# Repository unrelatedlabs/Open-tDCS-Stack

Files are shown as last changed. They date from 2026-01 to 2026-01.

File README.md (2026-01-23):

<!--
SPDX-License-Identifier: CC-BY-SA-4.0
Copyright (C) 2024-2026 Peter Kuhar and OpenTDCS Contributors
-->

# Open-tDCS-Stack

Open-source transcranial Direct Current Stimulation (tDCS) device using the Seeed Studio XIAO BLE nRF52840.

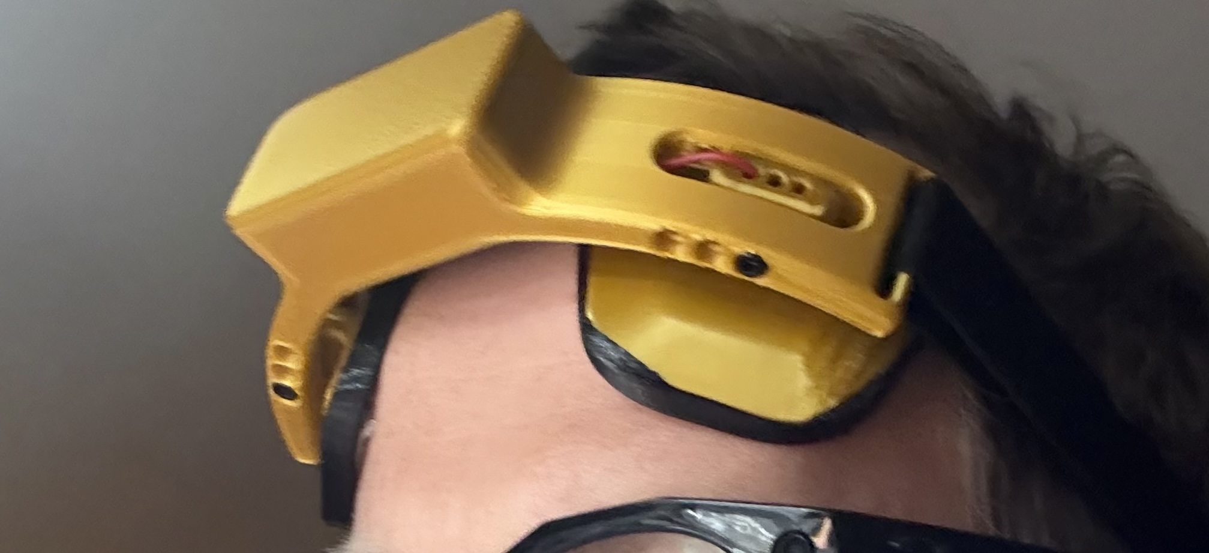
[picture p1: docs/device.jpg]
device photo
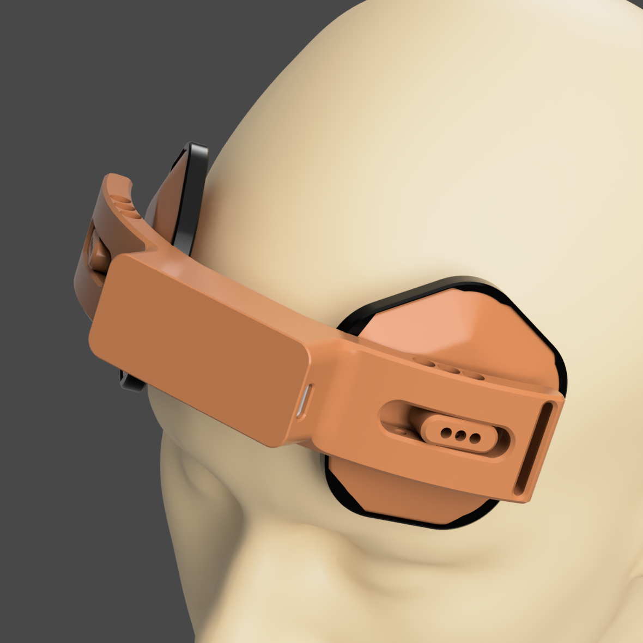
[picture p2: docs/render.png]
render
 

> Disclaimer: This is not a medical device. See `DISCLAIMER.md`.

## ⚠️ Safety Warning (tDCS / tES)

This open-source project is **not a certified medical device**. **Incorrect assembly, wiring, or electrode setup can cause dangerous current delivery**, leading to **skin burns/lesions**, unintended stimulation effects, equipment failure, or electric shock. tDCS/tES should only be performed with **medical-grade, certified equipment** and appropriate screening/supervision—**do not use DIY devices or unvalidated protocols on a person**.

### Sources
- IFCN (2015) "Transcranial electric stimulation in do-it-yourself applications" (PDF):  
  https://www.neurofyziologie.cz/doc/IFCNinfo/Using_tES_devices_as_DIY_FINAL_13Dec15.pdf
- Wurzman et al. (2016) "An open letter concerning do-it-yourself users of tDCS" (free full text, PMC):  
  https://pmc.ncbi.nlm.nih.gov/articles/PMC6050584/
- Fitz & Reiner (2015) "The challenge of crafting policy for do-it-yourself brain stimulation" (PubMed):  
  https://pubmed.ncbi.nlm.nih.gov/23733050/
- Bikson et al. (2016) "Safety of tDCS: Evidence-based update" (PubMed):  
  https://pubmed.ncbi.nlm.nih.gov/27372845/
- IFCN (Oct 2025) "Low intensity transcranial electric stimulation: Safety… guidelines 2017–2025 update" (PDF):  
  https://www.ifcn.info/UserFiles/file/CLINPH-S-25-01153_Targeted-Safety-Guidelines-update-Oct-2025.pdf
- Loo et al. (2011) "Avoiding skin burns with tDCS" (PubMed):  
  https://pubmed.ncbi.nlm.nih.gov/20923600/
- Rodríguez et al. (2014) "Skin lesions induced by tDCS" (PubMed):  
  https://pubmed.ncbi.nlm.nih.gov/25073936/
- "Skin Lesions Induced by tDCS" (PDF letter):  
  https://www.tmslab.org/publications/532.pdf
- Chao et al. (2018) "Hypomania induced by bifrontal tDCS" (free full text, PMC):  
  https://pmc.ncbi.nlm.nih.gov/articles/PMC6166027/

## Overview

Open-tDCS-Stack is a Bluetooth-enabled tDCS device that provides precise current control with real-time monitoring capabilities through a web interface.

## Hardware

- **Microcontroller**: Seeed Studio XIAO BLE nRF52840
- **Connectivity**: Bluetooth 5.0 (BLE)
- **Current Range**: 0-2.5mA (configurable)
- **Battery**: 3.7V LiPo

### Schematics 

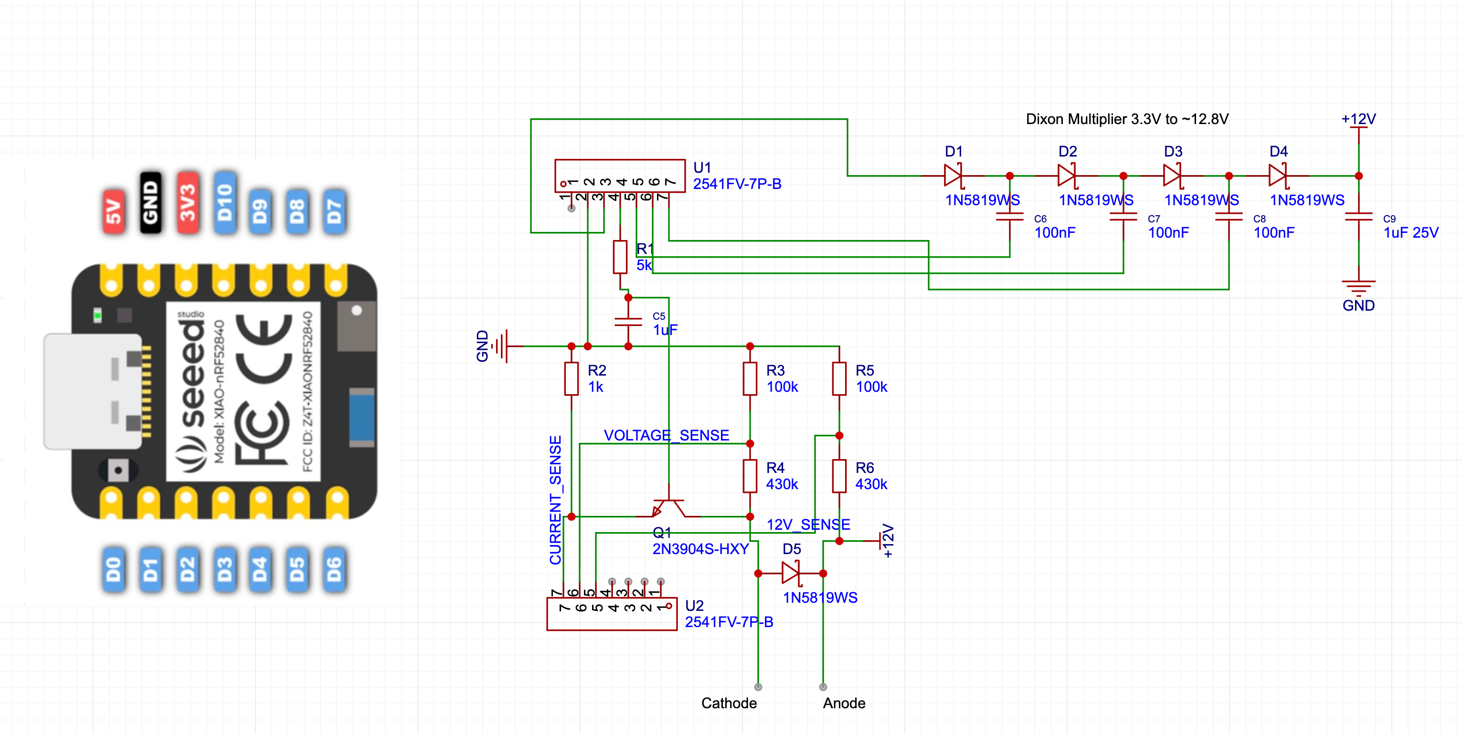
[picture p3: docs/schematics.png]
Open-tDCS Schematic


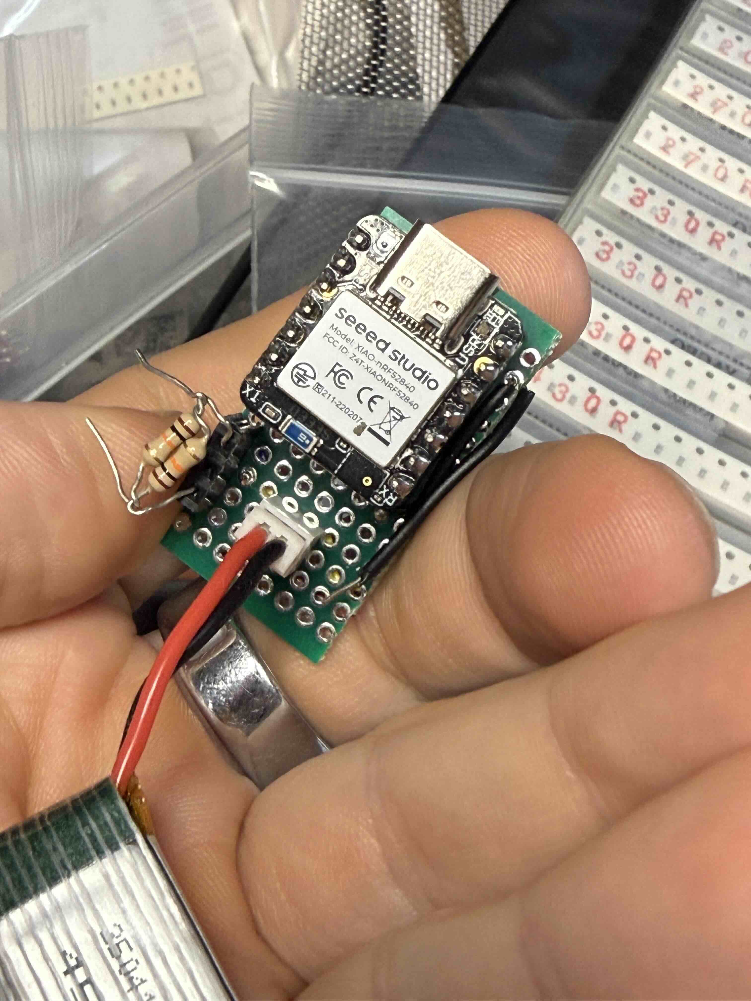
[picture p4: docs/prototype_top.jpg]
prototype top
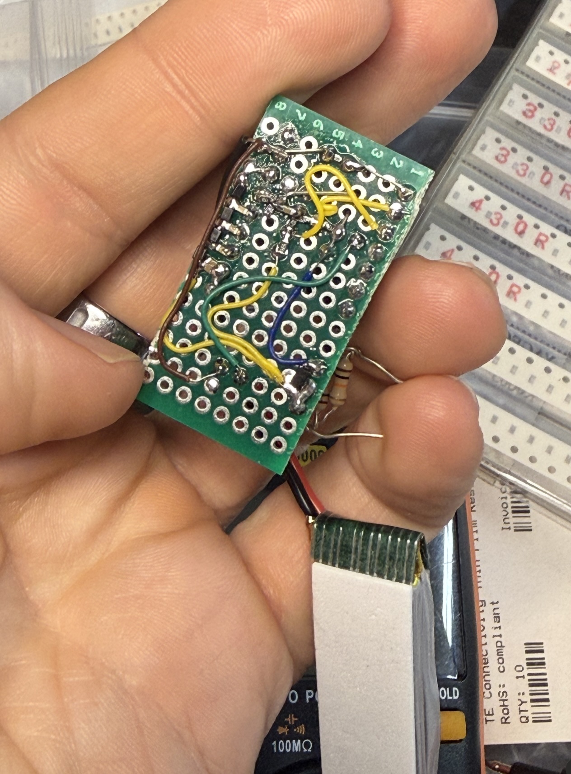
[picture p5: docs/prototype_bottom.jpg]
prototype bottom
 

### Printing 

Use a 3d printer. FDM is best, but resin should for with abs like resin for headband and electrodes and TPU like for the sponge retention. 

Print headband and electrodes in PLA or PETG and the sponge holder in TPU. Mine was printed on BambuLab P1S (PLA) and A1 Mini (TPU). 

## Firmware

The firmware is located in `firmware/build/opentdcs.ino.uf2`
To install on the XIAO BLE nRF52840. Place it into bootloader mode by quickly pressing the reset button twice. 
A XIAO USB drive will appear on your computer. Drag in the `firmware/build/opentdcs.ino.uf2` file. Done

(the UF2 file could be out of date. Please run `build.sh` in the `firmware` folder for an up to date build.)

### Features

- Real-time current monitoring and control
- Voltage monitoring: LiPo, compliance, output, electrode
- Electrode impedance calculation
- Configurable session parameters (duration, ramp up/down)
- BLE GATT service for wireless control
- Visual status indication via RGB LED
- Dickson charge pump voltage multiplier for 12V compliance voltage
- Test current (50µA) applied when connected but not in session

### Pin Usage

| Function | Pin | Description |
|---|-----|---|
| PWM Output | D10 | Current control signal |
| Current Sense | A0 | Measures output current via 1kΩ sense resistor |
| Output Voltage | A1 | Output voltage monitoring (5.3x divider) |
| Compliance Voltage | A2 | 12V monitoring (5.3x divider) |
| LiPo ADC | P0.31 | LiPo battery voltage (AIN7, 2.96x divider) |
| LiPo Enable | P0.14 | Pull-down to enable LiPo voltage divider |
| Multiplier A1 | D9 | Dickson charge pump driver |
| Multiplier B | D8 | Dickson charge pump driver (inverted) |
| Multiplier A2 | D7 | Dickson charge pump driver |

### LED Status

| State | Color | Pattern |
|---|---|---|
| Idle/Advertising | Green | Blink (50ms every 4s) |
| Connected | Blue | Solid |
| Session Active | Red | Solid |

## Web Interface

TLDR: Web UI is hosted at https://unrelatedlabs.github.io/Open-tDCS-Stack/gui/

The web GUI is located in `gui/index.html` and provides:

- Device connection via Web Bluetooth API
- Session control and monitoring
- Real-time current and impedance graphs
- Session history tracking

### Readings Display

**Primary (large):**
- I set / I measured (mA)
- V electrode (compliance - output voltage)
- R electrode (kΩ impedance)

**Secondary (small):**
- V lipo (battery)
- V compliance (Dickson output)
- V output

### Usage

1. Open in Web Bluetooth-compatible browser (Chrome, Edge). On iOS use the V Browser https://apps.apple.com/us/app/the-v-browser/id6446792641
2. Click "Connect Device" and select your tDCS device
3. Configure session parameters (current, duration, ramp time)
4. Start session and monitor real-time data

## Safety Notes

- This is an experimental device for research purposes only
- Always follow proper tDCS safety protocols
- Maximum current is limited to 4mA in hardware.
- Device includes impedance monitoring for electrode contact quality
- Automatic session termination on completion

Read the full disclaimer in `DISCLAIMER.md` before use.

## License

This project uses a multi-license approach:

| Component | License | SPDX Identifier |
|---|---|---|
| Hardware designs (schematics, 3D models) | [CERN-OHL-S-2.0](LICENSES/CERN-OHL-S-2.0.txt) | `CERN-OHL-S-2.0` |
| Software & firmware | [GPL-3.0](LICENSES/GPL-3.0.txt) | `GPL-3.0-or-later` |
| Documentation | [CC-BY-SA-4.0](LICENSES/CC-BY-SA-4.0.txt) | `CC-BY-SA-4.0` |

See [LICENSE](LICENSE) for full details.

## References

- [Seeed Studio XIAO BLE Documentation](https://wiki.seeedstudio.com/XIAO_BLE/)

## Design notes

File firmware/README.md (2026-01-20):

<!--
SPDX-License-Identifier: CC-BY-SA-4.0
Copyright (C) 2024-2026 Peter Kuhar and OpenTDCS Contributors
-->

# Open-tDCS-Stack Firmware

Firmware for the Seeed Studio XIAO BLE nRF52840 microcontroller.

## Building with Docker

The easiest way to build the firmware is using Docker:

```bash
./build.sh
```

This will:
1. Build the Docker image with Arduino CLI and required libraries
2. Compile the firmware
3. Generate a UF2 file in the `build/` directory

## Output

The build creates a UF2 file that can be flashed to the XIAO BLE nRF52840 by:
1. Double-clicking the reset button on the board
2. A USB drive will appear
3. Copy the UF2 file to the drive
4. The board will automatically flash and reboot

## Manual Building

If you prefer to build manually without Docker:

1. Install [Arduino CLI](https://arduino.github.io/arduino-cli/)
2. Add Seeed Studio board support:
   ```bash
   arduino-cli config add board_manager.additional_urls https://files.seeedstudio.com/arduino/package_seeeduino_boards_index.json
   arduino-cli core update-index
   arduino-cli core install Seeeduino:nrf52
   ```
3. Compile:
   ```bash
   arduino-cli compile --fqbn Seeeduino:nrf52:xiaonRF52840Sense opentdcs/opentdcs.ino
   ```
4. Convert to UF2 (optional, if not auto-generated):
   ```bash
   python3 ~/.arduino15/packages/Seeeduino/hardware/nrf52/1.1.12/tools/uf2conv/uf2conv.py \
     -c -f 0xADA52840 -o opentdcs.ino.uf2 opentdcs.ino.hex
   ```

## Requirements

- Docker (for containerized builds)
- OR Arduino CLI + Seeeduino nRF52 BSP (for manual builds)

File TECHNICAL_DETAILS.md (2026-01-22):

<!--
SPDX-License-Identifier: CC-BY-SA-4.0
Copyright (C) 2024-2026 Peter Kuhar and OpenTDCS Contributors
-->

# Technical Details

## BLE Service

### Service UUID
`a1b2c3d4-1234-5678-abcd-ef0123456789`

### Characteristics

**Measurement Characteristic** (Read, Notify)
UUID: `a1b2c3d5-1234-5678-abcd-ef0123456789`
Data format (12 bytes):
- Bytes 0-1: Set current (µA, little-endian uint16)
- Bytes 2-3: Measured current (µA, little-endian uint16)
- Bytes 4-5: Compliance voltage (mV, little-endian uint16)
- Bytes 6-7: Output voltage (mV, little-endian uint16)
- Bytes 8-9: Impedance (Ω, little-endian uint16, 0xFFFF if current < 10µA)
- Bytes 10-11: LiPo battery voltage (mV, little-endian uint16)

**Timer Characteristic** (Read, Write, Notify)
UUID: `a1b2c3d6-1234-5678-abcd-ef0123456789`

Write format (8 bytes) - to start/stop a session:
- Bytes 0-1: Target current (µA, little-endian uint16)
- Bytes 2-3: Total time (seconds, little-endian uint16)
- Bytes 4-5: Ramp up time (seconds, little-endian uint16)
- Bytes 6-7: Ramp down time (seconds, little-endian uint16)

Read/Notify format (8 bytes) - session status:
- Bytes 0-1: Target current (µA, little-endian uint16)
- Bytes 2-3: Time remaining (seconds, little-endian uint16)
- Bytes 4-5: Ramp up time (seconds, little-endian uint16)
- Bytes 6-7: Ramp down time (seconds, little-endian uint16)

To stop a session, write with totalTime=0 or targetCurrent=0.

## Hardware Constants

| Constant | Value | Description |
|---|---|---|
| ADC Reference | 3.3V | nRF52840 ADC reference voltage |
| ADC Resolution | 10-bit | 0-1023 range |
| PWM Resolution | 8-bit | 0-255 range |
| Sense Resistor | 1kΩ | Current measurement resistor |
| Output Voltage Divider | 5.3x | For measuring boosted output |
| Compliance Voltage Divider | 5.3x | For compliance voltage monitoring |
| LiPo Voltage Divider | 2.96x | 1M/510k divider, GPIO-enabled via P0.14 |
| Max Current | 4000µA | Hardware-limited maximum |
| Test Current | 50µA | Applied when connected, not in session |

## LiPo Battery Measurement

The XIAO BLE's LiPo battery is measured via a GPIO-enabled voltage divider:
- P0.31 (AIN7): ADC input
- P0.14: Pull-down enable (set LOW to enable divider, INPUT to disable)
- Divider: 1MΩ high-side, 510kΩ low-side (2.96x ratio)

The divider is normally disabled (P0.14 high-Z) to minimize battery drain. During measurement, P0.14 is set LOW briefly to complete the circuit.

## Voltage Measurements

The device measures and reports multiple voltages:

| Voltage | Source | Description |
|---|---|---|
| V compliance | A2 (5.3x divider) | Dickson charge pump output (~12V) |
| V output | A1 (5.3x divider) | Voltage at current source output |
| V lipo | P0.31 (2.96x divider) | XIAO LiPo battery voltage |
| V electrode | Calculated | V compliance - V output (voltage across electrodes) |

**Derived values:**
- Electrode voltage: `V_electrode = V_compliance - V_output`
- Electrode impedance: `R_electrode = V_electrode / I_measured`

## Dickson Charge Pump

The firmware drives a 3-pin Dickson voltage multiplier using HwPWM3:
- D9 and D7: Normal phase (50% duty cycle)
- D8: Inverted phase (180° out of phase)
- High-drive output mode enabled for increased current capability
- Multiplier is enabled when BLE connected or session active

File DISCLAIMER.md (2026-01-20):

<!--
SPDX-License-Identifier: CC-BY-SA-4.0
Copyright (C) 2024-2026 Peter Kuhar and OpenTDCS Contributors
-->

# Disclaimer

## ⚠️ Safety Warning

This open-source project is **not a certified medical device**. **Incorrect assembly, wiring, or electrode setup can cause dangerous current delivery**, leading to **skin burns/lesions**, unintended stimulation effects, equipment failure, or electric shock. tDCS/tES should only be performed with **medical-grade, certified equipment** and appropriate screening/supervision—**do not use DIY devices or unvalidated protocols on a person**.

## Terms

This project is for research and education only. By using, building, or modifying this project, you agree to the following:

- **No medical use**: Not approved for diagnosis or treatment. Do not use to self-treat any condition.
- **Your risk**: You assume all risks, including injury, discomfort, data loss, or property damage.
- **No warranty**: Provided "as is," without warranties or guarantees of safety, performance, or fitness.
- **No liability**: Contributors and maintainers are not liable for any direct or indirect damages.
- **Local laws**: You are responsible for complying with all applicable laws and regulations.
- **Health/implants**: Do not use if you have medical implants, epilepsy, skin lesions at electrode sites, or other contraindications. Consult a qualified clinician before any human use.
- **Supervision**: Do not use alone. Do not use on minors. Keep away from water and flammable environments.
- **Operation**: Verify electrode contact and polarity. Stop immediately on discomfort, pain, or adverse effects.
- **Power**: Use suitable batteries only. Inspect wiring. Avoid short circuits and overheating.
- **Research ethics**: If used with human subjects, follow institutional and ethical guidelines and obtain informed consent.

**If you do not accept these terms, do not use this project.**

## Sources

- IFCN (2015) "Transcranial electric stimulation in do-it-yourself applications" (PDF):  
  https://www.neurofyziologie.cz/doc/IFCNinfo/Using_tES_devices_as_DIY_FINAL_13Dec15.pdf
- Wurzman et al. (2016) "An open letter concerning do-it-yourself users of tDCS" (free full text, PMC):  
  https://pmc.ncbi.nlm.nih.gov/articles/PMC6050584/
- Fitz & Reiner (2015) "The challenge of crafting policy for do-it-yourself brain stimulation" (PubMed):  
  https://pubmed.ncbi.nlm.nih.gov/23733050/
- Bikson et al. (2016) "Safety of tDCS: Evidence-based update" (PubMed):  
  https://pubmed.ncbi.nlm.nih.gov/27372845/
- IFCN (Oct 2025) "Low intensity transcranial electric stimulation: Safety… guidelines 2017–2025 update" (PDF):  
  https://www.ifcn.info/UserFiles/file/CLINPH-S-25-01153_Targeted-Safety-Guidelines-update-Oct-2025.pdf
- Loo et al. (2011) "Avoiding skin burns with tDCS" (PubMed):  
  https://pubmed.ncbi.nlm.nih.gov/20923600/
- Rodríguez et al. (2014) "Skin lesions induced by tDCS" (PubMed):  
  https://pubmed.ncbi.nlm.nih.gov/25073936/
- "Skin Lesions Induced by tDCS" (PDF letter):  
  https://www.tmslab.org/publications/532.pdf
- Chao et al. (2018) "Hypomania induced by bifrontal tDCS" (free full text, PMC):  
  https://pmc.ncbi.nlm.nih.gov/articles/PMC6166027/

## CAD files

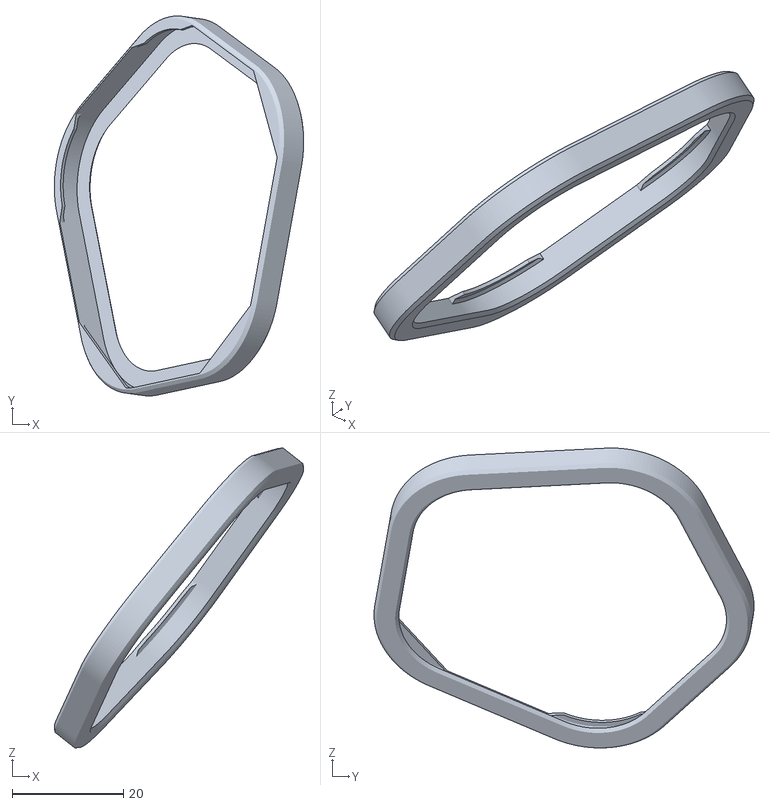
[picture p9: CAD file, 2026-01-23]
3d/sponge holder tpu.stl
44.8 x 68.3 x 53.9

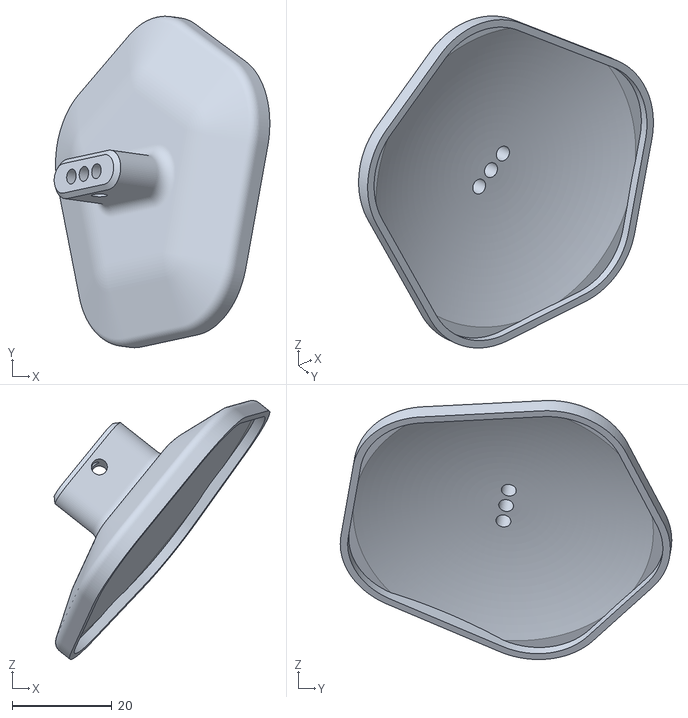
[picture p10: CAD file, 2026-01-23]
3d/electrode pad pla.stl
43.1 x 66.3 x 51.8

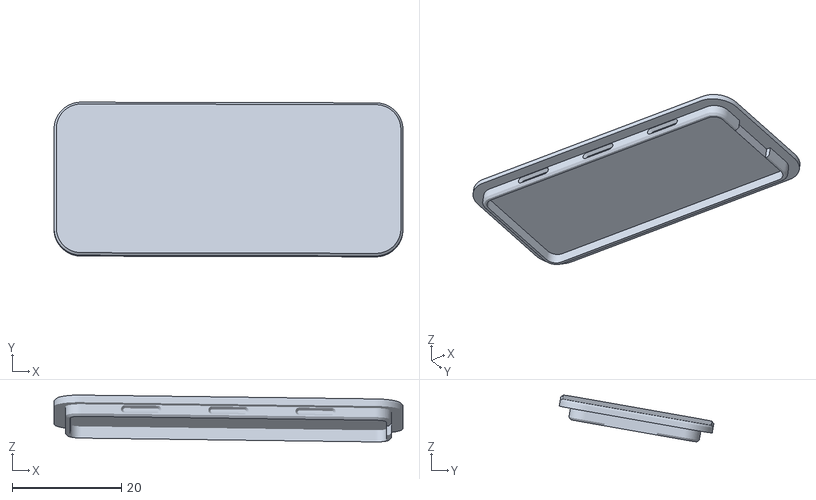
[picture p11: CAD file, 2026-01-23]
3d/cap pla.stl
64.0 x 28.4 x 8.60

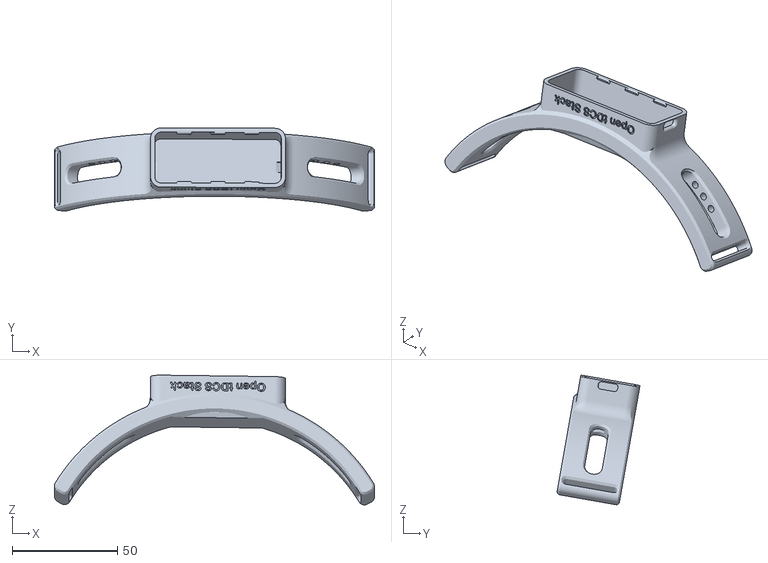
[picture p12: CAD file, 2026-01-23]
3d/headband pla.stl
151.7 x 39.4 x 61.5

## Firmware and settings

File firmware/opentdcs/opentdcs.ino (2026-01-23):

/*
 * OpenTDCS Firmware
 * Copyright (C) 2024-2026 Peter Kuhar and OpenTDCS Contributors
 *
 * SPDX-License-Identifier: GPL-3.0-or-later
 *
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
 * You should have received a copy of the GNU General Public License
 * along with this program. If not, see <https://www.gnu.org/licenses/>.
 */

#include <bluefruit.h>
#include <HardwarePWM.h>

const int PIN_PWM = 10;
const int PIN_ADC_CURRENT = A0;
const int PIN_ADC_OUTPUT = A1;
const int PIN_ADC_BATTERY = A2;

// LiPo battery measurement (XIAO internal)
const int PIN_LIPO_ENABLE = 14;  // P0.14 pull-down to enable divider
// P0.31 = AIN7, read via nRF52 SAADC directly

// Dickson multiplier pins
const int PIN_MULT_A1 = 9;   // D9 - drives with D7
const int PIN_MULT_B = 8;    // D8 - inverted
const int PIN_MULT_A2 = 7;   // D7 - drives with D9

// Dixon Multiplier PWM: 50% duty cycle
const uint16_t MULT_TOP = 16;    // PWM period 
const uint16_t MULT_DUTY = MULT_TOP/2;    // 50% duty

volatile bool multiplierEnabled = false;

const float ADC_REF = 3.3;
const float ADC_MAX = 1023.0;
const float RSENSE = 1000.0;
const float RBASE = 5000.0;    // base resistor
const float VBE = 0.65;         // base-emitter voltage
const float VDIV_OUT = 5.3;
const float VDIV_BAT = 5.3;
const float VDIV_LIPO = 2.96;  // (1M + 510k) / 510k

const uint16_t PWM_MAX = 255;  // 8-bit PWM
const uint16_t CURRENT_MAX_UA = 4000;
const uint16_t TEST_CURRENT_UA = 50;

// PID controller
const float KP = 0.02;   // conservative proportional
const float KI = 0.001;  // slow integral
const float INT_MAX = 50.0;  // max integral contribution (PWM counts)
float pidIntegral = 0;
float pidPwm = 0;

volatile uint16_t targetCurrent = 0;
volatile uint16_t totalTime = 0;
volatile uint16_t rampUp = 0;
volatile uint16_t rampDown = 0;
volatile uint16_t timeRemaining = 0;
volatile bool sessionActive = false;
volatile unsigned long sessionStart = 0;

uint16_t measuredCurrent = 0;
uint16_t batteryVoltage = 0;
uint16_t outputVoltage = 0;
uint16_t impedance = 0;
uint16_t setCurrent = 0;
uint16_t lipoVoltage = 0;

volatile bool isConnected = false;
uint8_t lastLedState = 0;  // 0=off, 1=green, 2=blue, 3=red

SoftwareTimer rampTimer;
SoftwareTimer measurementTimer;
SoftwareTimer blinkTimer;

BLEService tdcsService("a1b2c3d4-1234-5678-abcd-ef0123456789");
BLECharacteristic measChar("a1b2c3d5-1234-5678-abcd-ef0123456789", BLERead | BLENotify, 12);
BLECharacteristic timerChar("a1b2c3d6-1234-5678-abcd-ef0123456789", BLERead | BLEWrite | BLENotify, 8);

// Ownership token for HwPWM3 (any non-zero value)
#define MULT_PWM_TOKEN 0x4D554C54  // "MULT"

void setup() {
  Serial.begin(115200);
  while (!Serial && millis() < 3000);  // Wait up to 3s for serial
  Serial.println("Open-tDCS-Stack Starting...");

  // Reserve HwPWM3 for multiplier before analogWrite can claim it
  HwPWM3.takeOwnership(MULT_PWM_TOKEN);

  // Configure PWM: 8-bit resolution, ~62.5kHz frequency (16MHz / 256)
  analogWriteResolution(8);
  pinMode(PIN_PWM, OUTPUT);
  analogWrite(PIN_PWM, 0);  // Will use HwPWM0/1/2, not HwPWM3

  // Dickson multiplier pins use HwPWM3 (reserved above)

  pinMode(LED_RED, OUTPUT);
  pinMode(LED_GREEN, OUTPUT);
  pinMode(LED_BLUE, OUTPUT);
  ledOff();

  analogReadResolution(10);

  // LiPo measurement enable pin - start disabled (high-Z)
  pinMode(PIN_LIPO_ENABLE, INPUT);

  Bluefruit.begin();
  Bluefruit.autoConnLed(false);  // Disable automatic LED control
  Bluefruit.setTxPower(-4);
  Bluefruit.setName("tDCS");
  Bluefruit.Periph.setConnectCallback(onConnect);
  Bluefruit.Periph.setDisconnectCallback(onDisconnect);
  
  tdcsService.begin();
  measChar.begin();
  timerChar.setWriteCallback(onTimerWrite);
  timerChar.begin();
  
  startAdv();

  rampTimer.begin(20, rampCallback);
  // rampTimer starts only during sessions

  measurementTimer.begin(500, measurementCallback);
  measurementTimer.start();

  // Blink timer for idle state (50ms LED on)
  blinkTimer.begin(50, blinkOffCallback, NULL, false);  // one-shot (repeating=false)

  // Multiplier starts off, enabled when connected or session active
  updateLED();

  Serial.println("Initialization complete. Advertising...");

  suspendLoop();
}

void loop() {}

void rampCallback(TimerHandle_t _handle) {
  updateSession();
  if (sessionActive) updatePID();
}

void blinkOffCallback(TimerHandle_t _handle) {
  ledOff();  // Turn off LED after 50ms blink
}

void multiplierOn() {
  if (multiplierEnabled) return;
  multiplierEnabled = true;
  
  // Configure HwPWM3 for multiplier
  HwPWM3.setMaxValue(MULT_TOP);
  HwPWM3.addPin(PIN_MULT_A1);
  HwPWM3.addPin(PIN_MULT_B);
  HwPWM3.addPin(PIN_MULT_A2);
  
  // Write PWM values: D9/D7 normal, D8 inverted
  HwPWM3.writePin(PIN_MULT_A1, MULT_DUTY, false);  // D9 - normal
  HwPWM3.writePin(PIN_MULT_B,  MULT_DUTY, true);   // D8 - inverted
  HwPWM3.writePin(PIN_MULT_A2, MULT_DUTY, false);  // D7 - normal
  
  // Enable high drive on all pins after PWM is running
  pinMode(PIN_MULT_A1, OUTPUT_H0H1);
  pinMode(PIN_MULT_B,  OUTPUT_H0H1);
  pinMode(PIN_MULT_A2, OUTPUT_H0H1);
  
  Serial.println("Multiplier ON (HwPWM3, 50% duty, D8 inverted, high drive)");
}

void multiplierOff() {
  if (!multiplierEnabled) return;
  multiplierEnabled = false;
  
  // Set duty to 0 (outputs go low)
  HwPWM3.writePin(PIN_MULT_A1, 0, false);
  HwPWM3.writePin(PIN_MULT_B,  0, false);
  HwPWM3.writePin(PIN_MULT_A2, 0, false);
  
  // Remove pins and stop
  HwPWM3.removePin(PIN_MULT_A1);
  HwPWM3.removePin(PIN_MULT_B);
  HwPWM3.removePin(PIN_MULT_A2);
  HwPWM3.stop();
  
  Serial.println("Multiplier OFF");
}

void measurementCallback(TimerHandle_t _handle) {
  updateMeasurements();
  updateBLE();

  // Apply test current when connected but not in session
  if (!sessionActive) {
    if (isConnected) {
      setCurrent = TEST_CURRENT_UA;
      applyPWM(TEST_CURRENT_UA);
    } else {
      setCurrent = 0;
      applyPWM(0);
    }
  }

  // Periodic status logging
  if (sessionActive || isConnected) {
    Serial.print("Set:");
    Serial.print(setCurrent);
    Serial.print("uA I:");
    Serial.print(measuredCurrent);
    Serial.print("uA Z:");
    Serial.print(impedance);
    Serial.print("Ω Vbat:");
    Serial.print(batteryVoltage);
    Serial.print("mV Vout:");
    Serial.print(outputVoltage);
    Serial.print("mV Vlipo:");
    Serial.print(lipoVoltage);
    Serial.print("mV");
    if (sessionActive) {
      Serial.print(" T-");
      Serial.print(timeRemaining);
      Serial.print("s");
    }
    Serial.println();
  }
}

void startAdv() {
  Bluefruit.Advertising.addFlags(BLE_GAP_ADV_FLAGS_LE_ONLY_GENERAL_DISC_MODE);
  Bluefruit.Advertising.addService(tdcsService);
  Bluefruit.Advertising.addName();
  Bluefruit.Advertising.setInterval(160, 1600);
  Bluefruit.Advertising.setFastTimeout(30);
  Bluefruit.Advertising.start(0);
}

void onConnect(uint16_t conn) {
  isConnected = true;
  Serial.println("BLE Connected");
  multiplierOn();
  updateLED();
}

void onDisconnect(uint16_t conn, uint8_t reason) {
  isConnected = false;
  Serial.print("BLE Disconnected. Reason: ");
  Serial.println(reason);
  Bluefruit.Advertising.start(0);
  if (!sessionActive) {
    multiplierOff();
  }
  updateLED();
}

uint16_t readAIN7() {
  // Read P0.31 (AIN7) using nRF52 SAADC directly
  // Configure channel 0 for AIN7
  NRF_SAADC->RESOLUTION = SAADC_RESOLUTION_VAL_10bit;
  NRF_SAADC->CH[0].PSELP = SAADC_CH_PSELP_PSELP_AnalogInput7;
  NRF_SAADC->CH[0].PSELN = SAADC_CH_PSELN_PSELN_NC;
  NRF_SAADC->CH[0].CONFIG = (SAADC_CH_CONFIG_GAIN_Gain1_6 << SAADC_CH_CONFIG_GAIN_Pos) |
                            (SAADC_CH_CONFIG_REFSEL_Internal << SAADC_CH_CONFIG_REFSEL_Pos) |
                            (SAADC_CH_CONFIG_TACQ_10us << SAADC_CH_CONFIG_TACQ_Pos) |
                            (SAADC_CH_CONFIG_MODE_SE << SAADC_CH_CONFIG_MODE_Pos);
  
  volatile int16_t result;
  NRF_SAADC->RESULT.PTR = (uint32_t)&result;
  NRF_SAADC->RESULT.MAXCNT = 1;
  
  NRF_SAADC->ENABLE = SAADC_ENABLE_ENABLE_Enabled;
  NRF_SAADC->TASKS_START = 1;
  while (!NRF_SAADC->EVENTS_STARTED);
  NRF_SAADC->EVENTS_STARTED = 0;
  
  NRF_SAADC->TASKS_SAMPLE = 1;
  while (!NRF_SAADC->EVENTS_END);
  NRF_SAADC->EVENTS_END = 0;
  
  NRF_SAADC->TASKS_STOP = 1;
  while (!NRF_SAADC->EVENTS_STOPPED);
  NRF_SAADC->EVENTS_STOPPED = 0;
  
  NRF_SAADC->ENABLE = SAADC_ENABLE_ENABLE_Disabled;
  
  // Internal ref 0.6V, gain 1/6 = 3.6V range
  // Scale to match analogRead() 3.3V range: result * 3.6/3.3
  if (result < 0) result = 0;
  return (uint16_t)((result * 36UL) / 33UL);
}

void onTimerWrite(uint16_t conn, BLECharacteristic* chr, uint8_t* data, uint16_t len) {
  if (len >= 8) {
    targetCurrent = data[0] | (data[1] << 8);
    totalTime = data[2] | (data[3] << 8);
    rampUp = data[4] | (data[5] << 8);
    rampDown = data[6] | (data[7] << 8);

    if (totalTime > 0 && targetCurrent > 0) {
      timeRemaining = totalTime;
      sessionStart = millis();
      sessionActive = true;
      multiplierOn();  // Ensure multiplier is on for session
      rampTimer.start();
      updateLED();
      Serial.print("Session START: ");
      Serial.print(targetCurrent);
      Serial.print("uA, ");
      Serial.print(totalTime);
      Serial.print("s, ramp ");
      Serial.print(rampUp);
      Serial.print("/");
      Serial.println(rampDown);
    } else {
      if (sessionActive && setCurrent > 0) {
        // ramp down from current level over 5s
        targetCurrent = setCurrent;
        sessionStart = millis();
        totalTime = 5;
        rampUp = 0;
        rampDown = 5;
        timeRemaining = 5;
        Serial.println("Session STOPPING (5s ramp down)");
      } else {
        sessionActive = false;
        timeRemaining = 0;
        setCurrent = 0;
        rampTimer.stop();
        applyPWM(0);
        if (!isConnected) {
          multiplierOff();
        }
        updateLED();
        Serial.println("Session STOP");
      }
    }
  }
}

void updateMeasurements() {
  float vCurrent = analogRead(PIN_ADC_CURRENT) * ADC_REF / ADC_MAX;
  float vBattery = analogRead(PIN_ADC_BATTERY) * ADC_REF / ADC_MAX * VDIV_BAT;
  float vOutput = analogRead(PIN_ADC_OUTPUT) * ADC_REF / ADC_MAX * VDIV_OUT;
  
  // Read LiPo battery with GPIO-enabled divider
  pinMode(PIN_LIPO_ENABLE, OUTPUT);
  digitalWrite(PIN_LIPO_ENABLE, LOW);
  delayMicroseconds(100);
  float vLipo = readAIN7() * ADC_REF / ADC_MAX * VDIV_LIPO;
  pinMode(PIN_LIPO_ENABLE, INPUT);  // disable divider to save power
  
  // Total current through sense resistor
  float totalCurrentA = vCurrent / RSENSE;
  
  // Subtract base current: I_base = (V_pwm - Vbe - Vsense) / Rbase
  // V_pwm depends on setCurrent (same formula as applyPWM)
  float setCurrentA = setCurrent / 1000000.0;
  float vPwm = setCurrentA * RSENSE + VBE;
  float vBaseR = vPwm - VBE - vCurrent;
  float baseCurrentA = (vBaseR > 0) ? vBaseR / RBASE : 0;
  float currentA = totalCurrentA - baseCurrentA;
  if (currentA < 0) currentA = 0;
  
  measuredCurrent = (uint16_t)(currentA * 1000000);
  batteryVoltage = (uint16_t)(vBattery * 1000);
  outputVoltage = (uint16_t)(vOutput * 1000);
  lipoVoltage = (uint16_t)(vLipo * 1000);

  // Calculate impedance: R = V / I = (vBattery - vOutput) / current
  if (measuredCurrent > 10) {
    float electrodeV = vBattery - vOutput;
    impedance = (uint16_t)(electrodeV / currentA);
  } else {
    impedance = 0xFFFF;
  }
}

void updateSession() {
  if (sessionActive) {
    unsigned long elapsedMs = millis() - sessionStart;
    unsigned long elapsedSec = elapsedMs / 1000;
    unsigned long totalTimeMs = (unsigned long)totalTime * 1000;
    unsigned long rampUpMs = (unsigned long)rampUp * 1000;
    unsigned long rampDownMs = (unsigned long)rampDown * 1000;

    if (elapsedMs >= totalTimeMs) {
      sessionActive = false;
      timeRemaining = 0;
      setCurrent = 0;
      rampTimer.stop();
      applyPWM(0);
      if (!isConnected) {
        multiplierOff();
      }
      updateLED();
      Serial.println("Session COMPLETE");
      return;
    }

    timeRemaining = totalTime - elapsedSec;
    uint16_t current = targetCurrent;
    unsigned long remainingMs = totalTimeMs - elapsedMs;

    if (elapsedMs < rampUpMs && rampUp > 0) {
      current = ((unsigned long)targetCurrent * elapsedMs) / rampUpMs;
    } else if (remainingMs < rampDownMs && rampDown > 0) {
      current = ((unsigned long)targetCurrent * remainingMs) / rampDownMs;
    }

    setCurrent = current;
    // PID handles actual PWM output
  }
}

uint16_t readCurrentFast() {
  float vCurrent = analogRead(PIN_ADC_CURRENT) * ADC_REF / ADC_MAX;
  float totalCurrentA = vCurrent / RSENSE;
  
  // subtract base current: Ib = (Vpwm - Vbe - Vsense) / Rbase
  float vPwmActual = pidPwm * ADC_REF / PWM_MAX;
  float vBaseR = vPwmActual - VBE - vCurrent;
  float baseCurrentA = (vBaseR > 0) ? vBaseR / RBASE : 0;
  float currentA = totalCurrentA - baseCurrentA;
  if (currentA < 0) currentA = 0;
  
  return (uint16_t)(currentA * 1000000);
}

void updatePID() {
  if (setCurrent == 0) {
    pidIntegral = 0;
    pidPwm = 0;
    analogWrite(PIN_PWM, 0);
    return;
  }
  
  uint16_t current = readCurrentFast();
  float error = (float)setCurrent - (float)current;
  
  // feedforward: estimate PWM from desired current
  float currentA = setCurrent / 1000000.0;
  float vPwm = currentA * RSENSE + VBE;
  float feedforward = (vPwm / ADC_REF) * PWM_MAX;
  
  // PI correction with integral clamping
  pidIntegral += error;
  if (pidIntegral > INT_MAX / KI) pidIntegral = INT_MAX / KI;
  if (pidIntegral < -INT_MAX / KI) pidIntegral = -INT_MAX / KI;
  
  float correction = KP * error + KI * pidIntegral;
  pidPwm = feedforward + correction;
  
  if (pidPwm > PWM_MAX) pidPwm = PWM_MAX;
  if (pidPwm < 0) pidPwm = 0;
  
  analogWrite(PIN_PWM, (uint16_t)pidPwm);
  pinMode(PIN_PWM, OUTPUT_H0H1);
}

void applyPWM(uint16_t currentUA) {
  if (currentUA == 0) {
    pidIntegral = 0;
    pidPwm = 0;
    analogWrite(PIN_PWM, 0);
    return;
  }
  // open-loop for test current (non-session)
  float currentA = currentUA / 1000000.0;
  float vRsense = currentA * RSENSE;
  float vPwm = vRsense + VBE;
  uint16_t pwm = (uint16_t)(vPwm / ADC_REF * PWM_MAX);
  if (pwm > PWM_MAX) pwm = PWM_MAX;
  analogWrite(PIN_PWM, pwm);
  pinMode(PIN_PWM, OUTPUT_H0H1);
}

void updateBLE() {
  uint8_t meas[12];
  meas[0] = setCurrent & 0xFF;
  meas[1] = setCurrent >> 8;
  meas[2] = measuredCurrent & 0xFF;
  meas[3] = measuredCurrent >> 8;
  meas[4] = batteryVoltage & 0xFF;
  meas[5] = batteryVoltage >> 8;
  meas[6] = outputVoltage & 0xFF;
  meas[7] = outputVoltage >> 8;
  meas[8] = impedance & 0xFF;
  meas[9] = impedance >> 8;
  meas[10] = lipoVoltage & 0xFF;
  meas[11] = lipoVoltage >> 8;
  measChar.notify(meas, 12);
  
  uint8_t timer[8];
  timer[0] = targetCurrent & 0xFF;
  timer[1] = targetCurrent >> 8;
  timer[2] = timeRemaining & 0xFF;
  timer[3] = timeRemaining >> 8;
  timer[4] = rampUp & 0xFF;
  timer[5] = rampUp >> 8;
  timer[6] = rampDown & 0xFF;
  timer[7] = rampDown >> 8;
  timerChar.notify(timer, 8);
}

static unsigned long lastBlinkTime = 0;

void updateLED() {
  uint8_t newState;
  if (sessionActive) newState = 3;  // red (solid)
  else if (isConnected) newState = 2;  // blue (solid)
  else newState = 1;  // green (blinking)

  if (newState != lastLedState) {
    ledOff();
    blinkTimer.stop();
    if (newState == 3) ledRed();
    else if (newState == 2) ledBlue();
    // Green handled by blinking below
    lastLedState = newState;
    lastBlinkTime = 0;  // Reset blink timing
  }

  // Handle green blinking in idle state (50ms on every 4s)
  if (newState == 1) {
    unsigned long now = millis();
    if (now - lastBlinkTime >= 4000) {
      lastBlinkTime = now;
      ledGreen();
      blinkTimer.start();  // Turn off after 50ms
    }
  }
}

void ledOff() {
  digitalWrite(LED_RED, HIGH);
  digitalWrite(LED_GREEN, HIGH);
  digitalWrite(LED_BLUE, HIGH);
}

void ledRed() { digitalWrite(LED_RED, LOW); }
void ledGreen() { digitalWrite(LED_GREEN, LOW); }
void ledBlue() { digitalWrite(LED_BLUE, LOW); }

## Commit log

2026-01-08 3d files
    [HEADBAND.step, electrode pad.step, electrode pad.stl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]
2026-01-15 Refactor ADC pin assignments and update voltage divider constants in firmware. Adjust PWM calculation for improved current control. Update AGENTS.md to reflect changes in hardware configuration and m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
2026-01-15 Update firmware to enhance ADC functionality and improve PWM performance. Revise AGENTS.md for clarity on hardware changes and measurement processes.
2026-01-19 Updated the schematics
2026-01-19 updated readme and stl files
    [electrode pad.stl, headband.stl, sponge holder.stl]
2026-01-19 fixed schematics
2026-01-22 Added lipo measure. before PID
2026-01-23 pid control
2026-01-23 Updated the final schematics, 3d files, firmware and UI. Let's call this V1
    [HEADBAND.step, cap pla.stl, electrode pad pla.stl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]

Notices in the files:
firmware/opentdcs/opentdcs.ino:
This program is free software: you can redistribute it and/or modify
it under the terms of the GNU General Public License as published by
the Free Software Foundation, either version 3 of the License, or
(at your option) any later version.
